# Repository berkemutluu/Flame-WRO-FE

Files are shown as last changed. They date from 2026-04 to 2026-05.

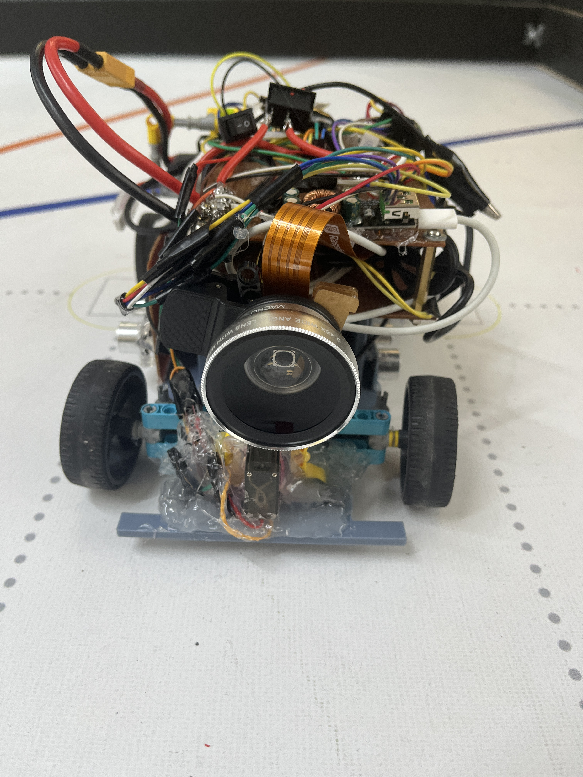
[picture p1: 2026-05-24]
Car_Photos/front.jpeg

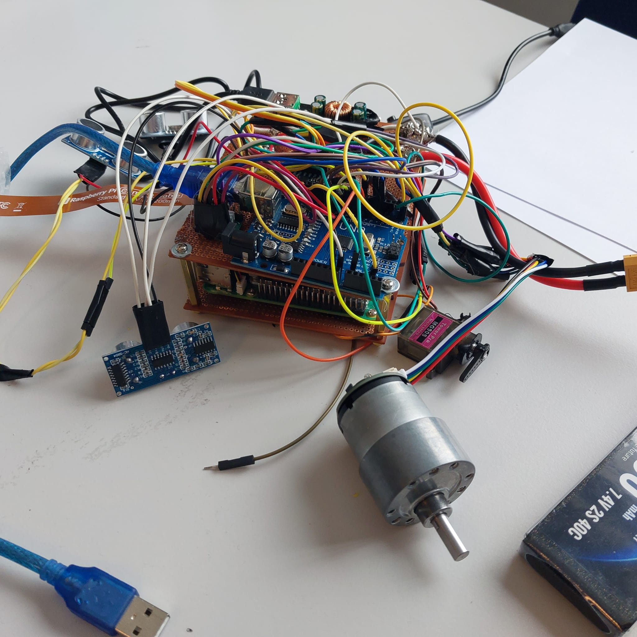
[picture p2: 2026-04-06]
Car_Photos/circuit-left.jpeg

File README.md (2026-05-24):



# WRO 2026: Future Engineers - Flame



## Table of Contents 

1. [Overview](#overview) 
2. [Design Process](#Design-Process)
3. [Car Photos](#carphoto)
4. [Mobility Management](#Mobility-Management)
    - [Chassis](#Chassis)
    - [Assembly Instructions](#assembly-instructions) 
    - [Driving Motor and Gearing](#Driving-Motor-and-Gearing)
    - [Steering and Differential Mechanism](#Steering-Mechanism)
    - [Battery](#Power-supply)
    - [Controllers](#Controllers)
    - [Sensors](#Sensors)
    - [Camera](#camera)
    - [Schematics](#schematics) 
    - [Components List](#components-list) 
5. [Software](#software) 
    - [Software Development](#software-development)
    - [Libraries Used in Runtime Files](#libraries-used-in-runtime-files)
    - [Programming Languages](#programming-languages) 
    - [Dependencies](#dependencies) 
    - [Repository Layout](#repository-layout)
    - [Code Installation and Run Guide](#code-installation-and-run-guide)
    - [Open Challenge](#open-challenge)
    - [Obstacle Challenge](#obstacle-challenge)
6. [System Thinking and Engineering Decisions](#system-thinking-and-engineering-decisions)
7. [Utilities](#utilities) 
    - [Failsafe Mechanisms](#failsafe)
    - [Debugging Tools](#debugging-tools) 
    - [Web Debug Interface](#web-debug-interface)
8. [Team Photos](#team-photos) 
9. [Demonstration Videos](#demonstration-videos) 
10. [Contributors](#contributors) 
11. [Resources](#sources) 

## Overview



Welcome to the official GitHub repository for Flame from Türkiye. This project documents the development of our autonomous vehicle designed to compete in the 2026 World Robot Olympiad (WRO) Future Engineers competition.



Our objective was to develop a high-performance autonomous vehicle capable of navigating complex tracks, avoiding obstacles, and recognizing traffic signals using OpenCV. For the 2026 season, we focused on a dual-controller architecture combining the high-speed image processing of a Raspberry Pi 5 with the real-time reliability of an Arduino Nano R4.

## Design Process

We moved through two major phases to reach our current build:

### Phase 1 (The LEGO Prototype): 

574065354-382b4c37-0c35-4aa0-9f4c-a3c25c82d3e3

574064939-b4bac3a6-0208-45d2-a44d-260d70b5efed-2

Initially, we built a frame using LEGO components and N20 Micro Gear Motor with an encoder. While excellent for rapid prototyping, the N20 motors lacked the torque required for consistent low-speed movement, and the LEGO frame exhibited structural flex under high-speed turns. Additionally, the placement of our micro servo to the lego chassis proved to be a challenge.

From this phase, we took note of what we need to improve:

- Soldering, instead of WAGO Connectors
    - These WAGO connectors really save time and effort when connecting components, but takes up a lot of unnecessary space. It was also nearly impossible to keep the wiring organized with these connectors in place.
- Chassis flex and play at joints: under acceleration and cornering, small connection tolerances introduced steering drift.
- Limited packaging freedom: The fixed structure of LEGO pieces limited our flexibility, making it challenging to position the electronics and sensors with the precision we aimed for.
- Center-of-mass inconsistency: battery and board placement options were limited, which affected balance between runs.
- Mounting rigidity for non-LEGO parts: integrating the motor, servo, and custom electronics required adapters and workarounds. 

### Phase 2 (The Custom 3D-Printed Build):

To solve the rigidity issues and to completely utilize the space we have, we designed a custom 3D-printed chassis. This allowed for a lower center of gravity and dedicated mounting points for the camera, steering, differential modules and sensors, significantly solving our problems. In short, Prototype 2 directly addressed the Phase 1 pain points: it improved rigidity, enabled cleaner wire/electronics routing, and gave us intentional component placement for better balance and repeatability. The robot is made of 3 parts: chassis, movement modules and electronics. The walls located in the center of the chassis houses the motor, while providing structual rigidity for the sandwich board of electronics mounted at the top. We designed the front and the back according to the measurements of our lego modules, resulting in a good placement. We adress the aspects of these in detail in the following chapters



### Car Photos

Here are our official photos of our car:






For high resolution pictures, please visit: [Car Photos](#carphoto)

### Mobility Management 

### Chassis

For fast prototyping, we first used lego for our chassis. Using a lego technic crane as an example we developed a small car-like chassis. However, this proved limiting for the robot: issues with accuracy and structural sag reduced its performance, while the lack of true customizability made it difficult to position electronics as needed and prevented us from using the available space efficiently. Additionally we couldn't really place electronics where we wanted, because of the lack of real customasibility. So, we wanted to go with a 3d printed chassis. First we wanted to test the motor and differential placement, and how it holds the weight our robot. This first version was designed to have a steering system that was 3d printed. But since we changed this, we also changed our chassis. We realized that our previously built circuit—a two-layer copper “sandwich” board—needed a more stable and secure mounting. So with these in mind, we extended the motor mounting walls to the side to provide a stable place to mount the electronics, achiveing a good center of mass. These side walls also enabled us to mount the side ultrasonic sensors in Version 2. 

The chassis we inspired from:

WhatsApp Image 2026-02-14 at 15 19 25

Lego Chassis:

574065354-382b4c37-0c35-4aa0-9f4c-a3c25c82d3e3

First Version - 3D Printed:



Second Version - 3D printed; with more structural stability which includes additional side walls for the electronics and the side ultrasonic sensors:



For more sketches of the chassis please visit the [3d-print files](./3d-print%20files/)

### Tires:

In our tests we compared 3 different tires from 2 different manufacturers. We tested the tires that were included in the spike prime lego set, standard tires from clementoni and onother set from the EV3 set.  Because of their lack of traction, we could not achieve good results with with the blue spike tires. Instead; we used the heavy-duty ev3 lego tires which have much better traction for the rear tires because of them being flexible rubber. Meanwhile, for the steering axle we used hard ones from clementino with grooves. 







### Assembly Instructions

To reproduce our robot, follow the sequence below.

1. **Prepare all files and parts**
   - 3D print all chassis parts from [`3d-print files`](3d-print%20files):
     - `chassis.stl`
     - `servo_adapter.stl`
     - `dc-motor_adapter.stl`
   - Open the wiring design in [`Schematic/wro.fzz`](Schematic/wro.fzz) with the Fritzing desktop app.
   - Download and prepare the LEGO module manuals from [`lego models && instructions`](lego%20models%20%26%26%20instructions):
     - `differential.pdf`
     - `steeringa.pdf`
   - Confirm all electronics and mechanical items from the Components List are available.

2. **Assemble the electronics**
   - Wire every component according to the [Schematics](#schematics) section and `Schematic/wro.fzz`.
   - Mount the control boards, regulators, and wiring on the top sandwich board.
   - Secure parts with screws/zip ties and use silicone supports where required.
   - Keep wiring away from moving drivetrain and steering parts.



3. **Build the LEGO modules**
   - Build the differential module from `differential.pdf`.
   - Build the steering module from `steeringa.pdf`.
   - Verify both modules move smoothly before mounting.

Differential:



Steering:



4. **Final mechanical integration**
   - Mount the JGB37-520 motor to the chassis center wall with M3 screws.
   - Connect the motor to the differential via the printed motor adapter.
   - Mount differential and steering modules on the chassis using silicone supports.
   - Connect the servo horn to the LEGO steering module and check full travel.
   - Install the sandwich board on the upper supports and route all cables cleanly.
   - Connect the battery last and confirm emergency access to the main power switch.



### Driving Motor and Gearing

 In our first LEGO prototype, we used an N20 6V motor, but it proved too small and lacked sufficient torque for our robot. As a result, the robot moved very slowly and responded poorly to low-speed commands, sometimes failing to move at all when a slow motion was required. We didn't want to use a 12v motor first becuase our battery was 7.4 volts. After some research, we realized that the motor driver, the L298N, might be part of the problem. Due to its low efficiency, it was not able to deliver enough power for proper performance. It also caused some voltage sag. The L298 family dissipates about 1.4V as heat, which further reduces efficiency. In addition, the minimum PWM value for speed control did not provide a smooth or usable range for precise adjustments. So we first tried to change the driver to a much more efficent, space saving and advanced component, the DRV8874. We tried it with advanced pwm controls but we couldn't solve it. The last option for us was upgrading the motor to the JGB37-520 which is 12v. We intentionally bought a high rpm version, so we could give it the same 7.4v but it could deliver the same speed we want, while increasing the torque. This was a success. This motor really outperformed the old n20 and delivered great driving to our robot. We used two m3 screws to attach this motor to our chassis, and a lego adapter to connect to motor to the differential module. This way we achieved a 1:1 gear ratio, motor starts at much lower PWM values and the braking distance is much shorter.

Old L298N:


New DRV8874:



Old n20 6V

We switched from the L298N to the DRV8874 before eventually upgrading the motor itself. The DRV8874 is a significant improvement: it is far smaller, has near-zero drop voltage (vs. ~1.4 V on the L298N), and supports efficient PWM control with a much wider effective duty-cycle range at low speeds.

### Steering and Differential Mechanism

We wanted to use steering and differential module that were 3d printed, but after several prints the parts did not hold up and caused anomalies. 

Expected outcome:





Broken guide rail after the first try:



After this experience, we decided to stick with lego for these modules. Lego parts were much more durable due to them being injection molded. Then we designed them and mounted them on the chassis with silicone.





### Battery



We use a 7.4 V-Lithium-polymer battery as our main power supply.
Per our research, we did not want to use a 11.1 V Lipo, as this one is very heavy, compared to the 2-cell version. We wanted to use a high-capacity one, becuase the Raspberry Pi is very Power-hungry when doing image processing. 
The on/off switch is located directly on the top of the robot for ease of access in an emergency. The step down convertor powers all of our sensors and motor at 5v. Also to not put strain on the LM2596, we used a high capacity PD 3.0 compatible voltage regulator board to power the pi. The arduino gets its power by the usb-a to usb-c cable along with serial communication with the pi.

See the schematics for details on connections.
[Schematics](#schematics)

#### Power Budget

To ensure the battery and regulators can handle the full electrical load, we estimated the peak and average current draw for each subsystem:

| Component | Supply Rail | Avg. Current | Peak Current |
|---|---|---|---|
| Raspberry Pi 5 (8GB, image processing) | 5 V (PD 3.0 board) | ~2.0 A | ~3.0 A |
| Arduino Nano R4 | 5 V (via USB-C from Pi) | ~30 mA | ~100 mA |
| JGB37-520 Motor (at 7.4 V) | 7.4 V (direct) | ~0.8 A | ~3.0 A (stall) |
| MG90S Servo | 5 V (LM2596) | ~150 mA | ~600 mA |
| HC-SR04 × 3 Ultrasonic Sensors | 5 V (XL4016) | ~45 mA | ~45 mA |
| MPU6050 IMU | 3.3 V (via Arduino) | ~4 mA | ~4 mA |
| TCS3200 Color Sensor | 5 V (XL4016) | ~2 mA | ~2 mA |
| DRV8874 Motor Driver (quiescent) | 7.4 V | ~1 mA | ~1 mA |

**5 V sensor rail (XL4016):** ~200 mA average — well within the 5 A rated capacity.

**Pi supply (PD 3.0 board):** Up to 3 A peak — we selected a QC 4.0/3.0 compatible module rated for 6–35 V input so it efficiently steps down from 7.4 V without the drop-voltage penalty of a linear regulator.

**Motor rail (7.4 V direct):** Average ~0.8 A, brief stall events up to ~3 A. The DRV8874 is rated for 3.5 A continuous / 5 A peak — adequate margin.

**Battery runtime estimate:** With a 3300 mAh cell and an average total draw of approximately 3.5 A across all rails, the theoretical runtime is ~56 minutes per charge. In practice we rotate between two battery packs between rounds.

We deliberately chose the 2-cell (7.4 V) LiPo over a 3-cell (11.1 V) because the 3-cell variant weighs roughly 30–40 g more for the same capacity and would require an additional high-power step-down stage for the motor. The 2-cell voltage is sufficient for the JGB37-520 at the RPM we need (we purchased the high-RPM variant specifically to offset the lower voltage).

### Controllers

For this season, we used a raspberry pi 5 and an arduino nano r4. We evaluated a single-controller design (Pi only), but kept a **dual-controller architecture** because actuator timing is more stable when low-level hardware control remains on a microcontroller.

#### Why two controllers?

- **Raspberry Pi 5 (high-level controller):**
  - Captures camera frames
  - Runs wall following, lap/section counting, and obstacle logic
  - Hosts the Flask web dashboard for live tuning and telemetry
  - Sends compact drive/steer commands to Arduino at fixed intervals

- **Arduino Nano R4 (real-time actuator controller):**
  - Executes steering servo commands immediately
  - Drives DC motor direction/PWM pins with low and predictable latency
  - Parses serial commands safely and applies bounds before output

This split lets the Pi focus on heavy image processing while Arduino handles deterministic motor/servo control.

#### Communication design (Pi ↔ Arduino)

We tested two serial methods:

1. **GPIO UART (TX/RX pins + level shifter)**  
   Not reliable in our setup because of 3.3 V (Pi) to 5 V (Arduino) level differences and intermittent link failures.

2. **USB serial (Pi USB-A to Arduino USB-C)**  
   This proved stable and simpler to maintain, so it became our final design.

Command flow is one-way for control:
- Pi sends line-based commands such as `STEER:<value>` and `DRIVE:<value>`
- Arduino validates and applies commands to hardware outputs

The link runs at **9600 baud** with a control update cadence around **20 Hz** (`send_interval = 0.05 s`).

#### Startup behavior and reliability

When USB serial is opened, Arduino may reset. To prevent unsafe movement during this phase, we use a startup handshake and safe defaults:

- Arduino starts with motor output in stop/coast state
- Pi waits for serial readiness before normal command streaming
- Control commands are only trusted after parser/connection readiness

This sequence avoids accidental motion during boot and makes power-up behavior repeatable in competition conditions.

### Sensors

Our car is equipped with a total of four sensors, not including the camera. Three of them are ultrasonic sensors, which allow for the detection of nearby obstacles.
In addition our vehicle has an IMU, the MPU6050, which is located in the top center of the robot.
Our IMU helps measure rotational movements, providing more precise control during straight sections and turns.

We have three ultrasonic sensors (hc-sr04) to measure distances to the left, the front and the right. In the opening race, some of the streets can be narrow. To avoid hitting a wall, the sensors detect the robot getting too close.

To run rather reliable turns and to go straight no matter which starting place, we use MPU6050 IMU sensor. 
This sensor has a gyroscope, an accelerometer and a compass onboard, but we only utilize the gyro.
However, gyroscopes tend to drift, when mounted on moving vehicles, that is why we use this data combined with the camera.

#### Sensor Calibration

**Ultrasonic sensors (HC-SR04):** The HC-SR04 outputs a distance in centimeters based on the echo pulse duration. We verified the accuracy by measuring a known distance of 20 cm in a controlled environment and confirming the returned value matched within ±1 cm. No software offset was needed.

**IMU (MPU6050) — gyroscope:** We initialize the IMU at robot startup while the robot is stationary. The first 100 readings are averaged to compute the zero-rate bias for each axis, which is then subtracted from subsequent readings. This removes the static offset and reduces apparent drift during straight driving.

**Camera HSV color thresholds:** The web dashboard (Flask UI) exposes all HSV lower and upper bounds for red, green, orange, and blue in real time. We calibrate under competition lighting by placing a pillar or line marker in the camera view and adjusting bounds using the live MJPEG stream until detection is stable and noise-free across at least 30 consecutive frames. Calibrated values are saved to `config.json`.

### Camera

We wanted to use a high quality camera, which has a wide angle of view and is compatible with OpenCV. The native Raspberry Pi Camera 3 suited all of our needs, on paper. In reality despite it being a wide angle camera, it was not enough for the obstacle round. The objects did not sometimes appear on the camera view, which causes problems. 

To solve this, we added a **0.45x wide-angle 37mm clip-on lens** in front of the Raspberry Pi Camera 3 module. This lens increases the visible area in front of the robot, especially at close range where obstacle pillars were previously leaving the frame. With the wider field of view, near-edge obstacle detection became more reliable and gave the control loop earlier visual input for steering decisions.

front



### Schematics 

Circuit schematics and hardware layouts are available in the [Schematic folder](Schematic).

WRO Schematic

### Components List

### 1. Computing & Control

Main Controller: Raspberry Pi 5 (8GB RAM)

Cooling: Raspberry Pi 5 Active Cooler + Aluminum Heatsink Set

Storage: SanDisk Extreme Pro 32GB MicroSD Card

Power Input: USB-C Power Cable with Integrated Switch (Type-C)

Display Interface: Micro HDMI to HDMI Cable (1.5m)

Second Controller: ~~Arduino Uno r3 (clone)~~ (For the drivetrain and sensors) Changed to a arduino nano r4 for latency issues.

### 2. Perception & Sensing

Primary Camera: Raspberry Pi Camera Module 3 (Wide Angle)

Camera Connection: Standard-to-Mini Camera Ribbon Cable (20cm)

Camera Lens: 0.45x 37mm clip-on Lens

Inertial Measurement: MPU6050 6-Axis Accelerometer and Gyroscope Sensor 

Object Detection: HC-SR04 Ultrasonic Distance Sensors (3 units)

Color Detection: TCS3200 Color Recognition Sensor Module

### 3. Propulsion & Drive System

Main Drive Motor: JGB37-520 DC Gear Motor (12V, 1590 RPM)

Secondary/Testing Motor: JGA12-520 DC Gear Motor (6V, 1500 RPM)

Motor Driver: DRV8874 Single Brushed DC Motor Driver Carrier

### 4. Power Management

Battery: 3300mAh 7.4V 2S Li-Po Battery (2 units)

Voltage Regulation (Step-Down): XL4016 High-Power DC-DC Buck Converter (5A)

LM2596 DC-DC Buck Converter (3A)

Voltage Regulation (Step-Up): MT3608 Adjustable DC-DC Boost Converter (2 units)

Specialty Power: USB-C QC4.0/QC3.0 Fast Charging Module (6V-35V Input)

### 5. Wiring & Connectivity

Connectors: XT60 Male Connection Cables (12AWG)

XT60 to Banana Plug Adapter Cable

DC Barrel Jack with Terminal Block

Wiring: 14 AWG High-Flex Silicone Wire (Red and Black)

~~Rapid Wire Connection Kit (55 pieces)~~ We decided to ditch this in favor of soldering. These WAGO connectors really save time and effort when connecting components, but takes up a lot of space. Also, it was nearly impossible to tidy our wires with these connectores attached.

Management: Cable Tie/Zip Tie Set

### 6. Mechanical Hardware

Fasteners: Assorted Screw and Nut Set (200 pieces)

M2 Screws and Nuts (8mm)

M4 Screws (6mm & 12mm), Washers, and Nuts

### 7. 3D-Printed Parts

Our robot has a total of 3 pieces which are 3d printed. Theses are:

the chassis, 

MG90s servo to lego adapter

and our JGB37-520 motor to lego adapter. 
Developing these parts took a lot of trial and error mainly because of tolerances. The printed parts did not expecatations, mainly because of durability reasons, but we have fixed this by increasing the infill rate of our adapters. This way we could combine the high-quality and durable lego parts with our motors.




# Software  

## Software Development  
  
The software is split into two controllers that cooperate during every driving cycle:  
  
1. **Raspberry Pi 5 (`raspy/robot_runtime.py`, Python)**  
   - Captures frames from the Raspberry Pi camera with `picamera2`  
   - Uses OpenCV/NumPy to crop the camera view, detect wall masks, floor markers, and red/green pillars  
   - Runs the driving state machine and computes steering/speed decisions  
   - Hosts the live preview, configuration, calibration, status, and manual-test web interface  
   - Writes decision records to one JSONL log file for review after a run  
   - Sends compact serial commands to the actuator controller  
2. **Arduino Nano (`arduino_outputProxy/drive_bridge/src/main.cpp`, C++ / Arduino framework)**  
   - Receives `STEER`, `DRIVE`, and `STOP` commands over USB serial  
   - Drives the steering servo with bounded absolute angles  
   - Drives the DC motor through the configured H-bridge pins with ramp limiting and timeout stop  
   - Keeps low-level actuator timing separate from Linux scheduling on the Pi  
  
The Pi makes the navigation decisions; the Arduino executes low-latency hardware actions. The WRO 2026 rules require the vehicle to drive autonomously, follow the randomly chosen round direction, complete three laps, and in the obstacle challenge pass red pillars on the right and green pillars on the left. The software is organized around those decisions.  
  
### Libraries Used in Runtime Files  
  
#### `arduino_outputProxy/drive_bridge/src/main.cpp` (Arduino/C++)  
- `Arduino.h`  
- `Servo.h`  
  
#### `raspy/robot_runtime.py` and modules (Python)  
- Standard library: `argparse`, `glob`, `json`, `os`, `threading`, `time`, `http.server`  
- Third-party: `cv2` (OpenCV), `numpy`  
- Optional/hardware-specific: `serial` (pyserial), `picamera2`  

### Programming Languages  
  
| Controller | Language | IDE / Toolchain |  
|---|---|---|
| Raspberry Pi 5 | Python 3 | Visual Studio Code / terminal |  
| Arduino Nano | C++ (Arduino framework) | PlatformIO / Arduino toolchain |  
  
We chose **Python** for the Pi because OpenCV and Picamera2 make camera-based tuning fast. **C++** on the Arduino is used for bounded, deterministic servo and motor output.  

### Dependencies  
  
**Raspberry Pi (Python):**  
  
| Package | Version / Notes | Purpose |  
|---|---|---|
| `opencv-python` (`cv2`) | 4.x | Color masks, contours, preview overlay, JPEG encoding |  
| `numpy` | 1.x | Array operations for frame processing |  
| `pyserial` | 3.x | USB serial communication with Arduino |  
| `picamera2` | Raspberry Pi OS package | Raspberry Pi camera capture |  
  
**Arduino Nano (C++):**  
  
| Library | Source | Purpose |  
|---|---|---|
| `Servo.h` | `arduino-libraries/Servo@^1.2.2` | Steering servo PWM control |  
| `Arduino.h` | Arduino framework | Core hardware access, serial, GPIO, timers |  
  
**Build and service tools:**  
  
| Tool | Purpose |  
|---|---|
| `platformio` | Build and upload the Arduino firmware |  
| `systemctl` | Install, enable, start, stop, and inspect the Pi runtime service |  
  
### Repository Layout  
  
| Path | Purpose |  
|---|---|
| `main.py` | Root launcher that adds `raspy/` to `sys.path` and calls `robot_runtime.main` |  
| `raspy/robot_runtime.py` | Main Pi runtime, camera loop, serial link, CLI, and `RobotRunner` |  
| `raspy/vision_pipeline.py` | HSV masks, wall mask extraction, pillar contour detection |  
| `raspy/vision_types.py` | Shared `Pillar` data object and ROI helper |  
| `raspy/drive_state.py` | State machine for starting, centering, turning, tracking pillars, avoiding pillars, and done state |  
| `raspy/lap_direction.py` | Black-wall edge voting used to infer clockwise/counter-clockwise direction |  
| `raspy/settings.py` / `raspy/settings.json` | Default settings and tuned runtime configuration |  
| `raspy/control_panel.py` | Built-in HTTP control/configuration dashboard and MJPEG preview |  
| `raspy/decision_log.py` | Central JSONL decision logger, replaced on each run |  
| `raspy/install_vehicle_service.sh` | Installs the systemd service file on the Raspberry Pi |  
| `raspy/vehicle-runtime.service` | systemd unit for starting `robot_runtime.py --pillars` on boot |  
| `arduino_outputProxy/drive_bridge/src/main.cpp` | Arduino firmware for serial parsing and actuator output |  
| `arduino_outputProxy/drive_bridge/platformio.ini` | PlatformIO firmware project configuration |  
  
### Code Installation and Run Guide  
  
Use this sequence on a Raspberry Pi 5 + Arduino Nano setup.  
  
1. **Flash the Arduino controller**  
   - Install PlatformIO if `platformio` is not already available.  
   - From repository root:  
     - `cd arduino_outputProxy/drive_bridge`  
     - `platformio run --target upload`  
   - The checked-in PlatformIO environment and board are both `nanoatmega328new`.  
   - Serial monitor speed is `9600`. On startup the Arduino prints `READY`.  
  
2. **Prepare Python runtime on Raspberry Pi**  
   - From repository root:  
     - `python3 -m venv .venv`  
     - `source .venv/bin/activate`  
     - `pip install --upgrade pip`  
     - `pip install opencv-python numpy pyserial`  
   - Install `picamera2` from the Raspberry Pi OS packages if it is not already present.  
   - `robot_runtime.py` imports `cv2` during startup, so even `--print-config` requires OpenCV to be installed.  
  
3. **Connect hardware**  
   - Connect Arduino to Raspberry Pi over USB.  
   - Confirm Arduino appears as `/dev/ttyACM0` or `/dev/ttyUSB0`; auto-detect is enabled in `raspy/settings.json`.  
   - Connect and enable the Raspberry Pi camera.  
  
4. **Run the robot software**  
   - From repository root:  
     - `python3 main.py --pillars`  
   - Or run the runtime module directly:  
     - `cd raspy`  
     - `python3 robot_runtime.py --pillars`  
   - For a camera run without Arduino output:  
     - `python3 robot_runtime.py --no-serial --max-frames 20`  
   - `--no-serial` disables USB command output only; it still needs OpenCV, Picamera2, and an enabled camera.  
   - The web dashboard is served at `http://<raspberry-pi-ip>:5000/`.  
  
5. **Useful runtime options**  
   - `--config PATH` loads a different settings file  
   - `--set path=value` overrides one setting, for example `--set control.speed=120`  
   - `--save-config` writes overrides back to the settings file  
   - `--print-config` prints the effective configuration and exits  
   - `--fixed-dir -1|0|1` sets clockwise, auto, or counter-clockwise direction behavior  
   - `--web` / `--no-web` enables or disables the dashboard  
  
6. **Before track runs**  
   - Verify steering direction, motor direction, and serial port.  
   - Open `/video_feed` or the dashboard preview and confirm wall, marker, and pillar overlays.  
   - Use Color Sampling in the dashboard to tune HSV thresholds, then save with **Save Config**.  
   - Check `raspy/decision_log.jsonl` after a run to review state changes and drive decisions.  
  
7. **Optional systemd startup service**  
   - The service assumes the deployed project is at `/home/pi/program`, so the runtime path is `/home/pi/program/raspy/robot_runtime.py`.  
   - Copy or sync this repository to `/home/pi/program` before installing the service, or update `raspy/vehicle-runtime.service` to match the deployment path.  
   - Install the service from the repository checkout on the Pi:  
     - `raspy/install_vehicle_service.sh`  
   - Manage it with systemd:  
     - `sudo systemctl start vehicle-runtime.service`  
     - `sudo systemctl stop vehicle-runtime.service`  
     - `sudo systemctl enable vehicle-runtime.service`  
     - `sudo systemctl status vehicle-runtime.service`  
     - `journalctl -u vehicle-runtime.service -f`  
   - The service runs `python3 /home/pi/program/raspy/robot_runtime.py --pillars` with working directory `/home/pi/program/raspy`.  

---  

## Open Challenge  
  
The WRO 2026 Open Challenge has no traffic signs. The vehicle must drive in the randomly selected direction, complete three laps, and stop autonomously according to the round-end rules.  
  
### Strategy  
  
The implemented strategy is camera-based wall following with color-marker turn detection:  
  
1. **Frame preparation:** `PiCamera.capture_bgr` captures an RGB frame, converts it to BGR, rotates it 180 degrees when configured, and `Pipeline.crop` removes the top part of the image using `camera.crop_height`.  
  
2. **Wall detection:** `Pipeline.filter_RG_Bl` builds a dark wall mask from grayscale intensity and low HSV saturation. It excludes detected red, green, orange, blue, and pink areas so colored markers do not become wall pixels.  
  
3. **Line marker detection:** `Pipeline.filter_OB` builds orange and blue masks inside the configured `roi.line` rectangle. The state machine uses the orange/blue portions to schedule left/right turning states.  
  
4. **Round direction:** If `behavior.fixed_round_dir` is `0`, `lap_direction.find_round_dir` votes on wall-edge geometry until `behavior.round_dir_vote_threshold` is reached. A non-zero fixed direction skips the search.  
  
5. **PD steering:** In `PD-CENTER`, the controller compares the active wall portion against `pd.target_black_portion`. `pd.kp` and `pd.kd` convert the current error and previous error into a correction value.  
  
6. **State machine:** `drive_state.StateMachine` moves through `STARTING`, `PD-CENTER`, scheduled `TURNING-L` / `TURNING-R`, and finally `DONE`. When `turns_left` reaches zero, `DONE` is scheduled after `behavior.finish_delay_seconds`.  
  
7. **Output mapping:** The correction is clamped by `control.max_correction`, converted into a servo offset with `control.max_steering_offset`, bounded to `servo_min_deg..servo_max_deg`, and sent with the selected drive speed.  
  
### Turn Count and Stop Behavior  
  
The code stops through the state machine, not through a separate lap tracker. `StateMachine` initializes `turns_left` from `behavior.turns`, subtracts one when a valid direction-specific orange or blue marker schedules a turn, then schedules `DONE` once `turns_left <= 0`. In `DONE`, `RobotRunner` centers steering and sends zero drive speed.  
  
`settings.DEFAULT_CONFIG` uses `behavior.turns = 12`, which matches three laps on a four-section track. The checked-in tuned file `raspy/settings.json` currently uses `behavior.turns = 120`. The file does not label why this value is used, so it should be treated as the current tuned/test configuration, not the WRO three-lap stop value. For an official three-lap run, set `behavior.turns` to `12` or pass `--set behavior.turns=12`.  
  
---  

## Obstacle Challenge  
  
The WRO 2026 Obstacle Challenge adds red and green pillars as traffic signs. The rules require the robot to pass a red pillar on the right and a green pillar on the left.  
  
### Strategy  
  
1. **Base navigation:** The obstacle run uses the same wall mask, line-marker logic, direction voting, and PD centering as the Open Challenge.  
  
2. **Pillar detection:** `Pipeline.get_pillars` finds red and green contours after median blur and morphological cleanup. Small, narrow, short, or low-fill contours are discarded using the `contours` settings.  
  
3. **Pillar stabilization:** `RobotRunner.stabilize_pillars` keeps one closest pillar track, smooths its area with an EMA, requires confirm frames, and can hold a recently lost pillar for a few frames.  
  
4. **Ignore check:** A pillar can be ignored when orange or blue marker pixels are found inside the narrow pillar ROI. This avoids treating track markers as traffic pillars.  
  
5. **Tracking and avoiding:** In pillar rounds, a confirmed pillar can move the state machine from `PD-CENTER` to `TRACKING-PILLAR`. A larger confirmed pillar changes the state to `AVOIDING-R` for red or `AVOIDING-G` for green.  
  
6. **Avoidance correction:** Avoidance uses a first phase and second phase correction (`pillar_red_first_correction`, `pillar_red_second_correction`, `pillar_green_first_correction`, `pillar_green_second_correction`). The wall guard can override this if one wall portion becomes too high.  
  
7. **Return to center:** After `behavior.pillar_avoid_seconds`, the state machine returns to `PD-CENTER` and enforces a cooldown before another avoid decision.  

---  
  
## Raspberry Pi Software (`raspy/robot_runtime.py`) — Process Sections  
  
### Section A — Boot and initialization  
  
- Load persisted configuration from `raspy/settings.json`  
- Merge missing keys from `settings.DEFAULT_CONFIG`  
- Apply CLI overrides such as `--pillars`, `--fixed-dir`, `--set`, and web options  
- Initialize `Pipeline`, `StateMachine`, `ArduinoLink`, `PiCamera`, and `DecisionLogger`  
- Start Arduino serial, camera capture, and the optional web server  
  
`settings.ConfigLoader` also accepts a few older configuration keys (`ArduinoSerialPort`, `PD`, and `ROI`) and maps them into the current nested settings structure. New changes should use the current keys shown in `raspy/settings.json`.  
  
### Section B — Frame acquisition and preprocessing  
  
Per frame, the Pi does the following:  
  
1. Capture a frame from Picamera2  
2. Convert RGB to BGR  
3. Rotate 180 degrees when `camera.flip_180 = true`  
4. Crop using `camera.crop_height`  
5. Convert the cropped image to HSV for color masks  
  
### Section C — Vision section  
  
`vision_pipeline.Pipeline` produces the lightweight inputs used by the state machine:  
  
- Orange and blue marker portions from `roi.line`  
- Left and right wall portions from `roi.left_wall` and `roi.right_wall`  
- Red and green pillar candidates from contour area, width, height, and fill ratio  
- Optional pink parking mask helper (`filter_parking`)  
  
### Section D — State and decision section  
  
`drive_state.StateMachine` owns the high-level driving state:  
  
- `STARTING` waits for a direction or confirmed pillar condition  
- `PD-CENTER` performs normal wall following  
- `TRACKING-PILLAR` steers based on pillar x-position  
- `AVOIDING-R` and `AVOIDING-G` use timed avoidance corrections  
- `TURNING-L` and `TURNING-R` apply full correction for corner turns  
- `DONE` forces speed to zero  
  
Important behavior settings include:  
  
- `line_marker_min_portion` for orange/blue marker detection  
- `turn_delay_seconds`, `pillar_turn_delay_seconds`, and `turn_timeout_seconds` for turns  
- `pillar_track_area`, `pillar_avoid_area`, and confirm-frame settings for obstacle behavior  
- `pillar_wall_guard_threshold` and `pillar_wall_guard_correction` for wall protection during avoidance  
  
### Section E — Serial command output  
  
`ArduinoLink` sends line-oriented actuator commands:  
  
- `STEER:<int>`  
- `DRIVE:<int>`  
- `STOP`  
  
The port is auto-detected from `/dev/ttyACM*`, `/dev/ttyUSB*`, or pyserial port listing unless auto-detect is disabled. Commands are paced by `send_interval_seconds` and repeated only after `keepalive_interval_seconds` when unchanged.  
  
### Section F — Web dashboard/API section  
  
The dashboard is served by Python's built-in `ThreadingHTTPServer`:  
  
- `GET /` dashboard  
- `GET /api/status` runtime telemetry  
- `GET /api/config` active config snapshot  
- `GET /video_feed` MJPEG stream  
- `POST /api/config` update one setting path  
- `POST /api/save` persist settings  
- `POST /api/command` manual `STEER`, `DRIVE`, or `STOP`  
- `POST /api/sample`, `/api/apply_sample`, `/api/apply_samples` for color calibration  
  
### Section G — Decision logging  
  
`decision_log.DecisionLogger` writes newline-delimited JSON to one file. By default this is `raspy/decision_log.jsonl`. The file is opened with write mode on startup, so each run replaces the previous decision log instead of creating timestamped logs.  
  
Logged events include:  
  
- `session_start` and `session_stop`  
- `runtime_start` and `runtime_error`  
- `round_direction_selected`  
- `state_update`  
- sampled `drive_output` decisions  
- `config_update` and `manual_command`  
  
Each record stores lightweight inputs, the selected decision/action, and already-computed reasoning values such as wall portions, marker portions, pillar snapshot, correction, PD error, previous error, gain values, vote totals, and manual override status. Raw frames are not written to the decision log.  
  
Console status output is separate from the decision log and is controlled by `debug.log_every_seconds`. Optional frame saving is controlled by `debug.save_frames`, `debug.frame_dir`, and `debug.frame_every_seconds`; when enabled, the runtime overwrites `latest.jpg` in the configured debug frame directory instead of storing a full video history.  
  
The sections above describe responsibilities by module.  
The next flowcharts switch perspective from static sections to **runtime execution order**. These show the steps involved from startup to each control decision.  
  
### Raspberry Pi High-Level Flow  
  
```mermaid  
flowchart TD  
    A[Start robot_runtime.py] --> B[Load settings.json and CLI overrides]  
    B --> C[Init Pipeline and StateMachine]  
    B --> D[Open decision_log.jsonl replacing old file]  
    B --> E[Connect Arduino and wait for READY]  
    E --> F[Start Picamera2]  
    F --> G{Web enabled}  
    G -- Yes --> H[Start ThreadingHTTPServer]  
    G -- No --> I[Skip dashboard]  
    H --> J[Control cycle]  
    I --> J  
    J --> K[Capture crop HSV frame]  
    K --> L[Build masks and pillars]  
    L --> M[Update state machine]  
    M --> N[Compute correction speed servo]  
    N --> O[Send STEER and DRIVE]  
    O --> P[Update preview status and decision log]  
    P --> J  
```  
  
### `RobotRunner.cycle` Detailed Flow  
  
```mermaid  
flowchart TD  
    A[Capture BGR frame] --> B[Crop and convert to HSV]  
    B --> C[Measure orange blue marker ROI]  
    B --> D[Measure left right wall ROIs]  
    B --> E[Detect and stabilize pillars]  
    C --> F[StateMachine should_transition_state]  
    D --> F  
    E --> F  
    F --> G{Searching for round direction}  
    G -- Yes --> H[Add wall-edge direction vote]  
    G -- No --> I[Keep current direction]  
    H --> J[Compute correction]  
    I --> J  
    J --> K[Map correction to servo angle]  
    K --> L[Select speed for state]  
    L --> M{Manual command active}  
    M -- Yes --> N[Override servo or drive output]  
    M -- No --> O[Use automatic output]  
    N --> P[Apply serial output]  
    O --> P  
    P --> Q[Update overlay status and logs]  
```  
  
### `StateMachine.should_transition_state` Flow  
  
```mermaid  
flowchart TD  
    A[Current state and sensor portions] --> B{Scheduled state due}  
    B -- Yes --> C[Transition to scheduled state]  
    B -- Blocking wait --> Z[Hold current state]  
    B -- No --> D{STARTING}  
    D -- Pillar confirmed --> E[TRACKING-PILLAR]  
    D -- Direction known --> F[PD-CENTER]  
    D -- Otherwise --> Z  
    F --> G{Turns left <= 0}  
    G -- Yes --> H[Schedule DONE]  
    G -- No --> I{Pillar round and pillar confirmed}  
    I -- Track area --> E  
    I -- Avoid area --> J[AVOIDING-R or AVOIDING-G]  
    I -- No --> K{Line marker detected}  
    E --> L{Pillar lost}  
    L -- Yes --> F  
    L -- No --> I  
    J --> M{Avoid timer elapsed}  
    M -- Yes --> F  
    M -- No --> Z  
    K -- Blue with clockwise dir --> N[Schedule TURNING-L]  
    K -- Orange with counter-clockwise dir --> O[Schedule TURNING-R]  
    K -- Otherwise --> Z  
    N --> Z  
    O --> Z  
```  
  
### `compute_correction` Flow  
  
```mermaid  
flowchart TD  
    A[State and measured inputs] --> B{State}  
    B -- TRACKING-PILLAR --> C[Error from pillar x offset]  
    B -- PD-CENTER --> D[Error from active wall portion]  
    B -- TURNING-L --> E[Correction -1.0]  
    B -- TURNING-R --> F[Correction 1.0]  
    B -- AVOIDING-R --> G[Red avoidance phase correction]  
    B -- AVOIDING-G --> H[Green avoidance phase correction]  
    B -- STARTING or DONE --> I[Correction 0.0]  
    C --> J[PD correction kp error plus kd delta]  
    D --> J  
    G --> K{Wall guard active}  
    H --> K  
    K -- Wall too close --> L[Use guard correction]  
    K -- Clear --> M[Use phase correction]  
    E --> N[Clamp and output]  
    F --> N  
    I --> N  
    J --> N  
    L --> N  
    M --> N  
```  
  
---  
  
## Arduino Software (`arduino_outputProxy/drive_bridge/src/main.cpp`) — Process Sections  
  
### Section 1 — Hardware constants and limits  
  
- `SERVO_PIN = 6`  
- `MOTOR_IN1_PIN = 10`  
- `MOTOR_IN2_PIN = 9`  
- Optional `MOTOR_PWM_PIN = 11` for one-PWM/two-direction wiring  
- Current motor mode: `USE_TWO_PWM_MOTOR_DRIVER = true` and `USE_SOFTWARE_PWM_FOR_TWO_PWM_DRIVER = true`  
- Physical enable input is currently disabled: `USE_ENABLE_PIN = false`, with `ENABLE_PIN = 7` reserved if enabled later  
- Steering bounds: `SERVO_MIN_DEG = 15`, `SERVO_CENTER_DEG = 90`, `SERVO_MAX_DEG = 165`  
- Motor output bound: `MOTOR_MAX_PWM = 200`  
- Ramp settings: `MOTOR_RAMP_INTERVAL_MS = 20`, `MOTOR_RAMP_STEP = 2`  
- Command timeout: `COMMAND_TIMEOUT_MS = 1000`  
- Command line buffer size: `LINE_BUF_SIZE = 64`  
  
### Section 2 — Setup phase  
  
`setup()` performs deterministic startup:  
  
- Configure motor pins and optional enable pin  
- Attach and center steering servo  
- Stop motor output  
- Start serial at `9600`  
- Emit `READY` after startup delay  
  
### Section 3 — Command receive and parse phase  
  
`loop()` and `handleCommand` implement a strict parser:  
  
1. Read bytes until newline  
2. Null-terminate the line buffer  
3. Split `NAME:VALUE` at the colon  
4. Parse the integer payload with `parseIntStrict`  
5. Execute only supported commands  
  
Supported commands:  
  
- `STOP`  
- `STEER:<int>`  
- `DRIVE:<int>`  
  
### Section 4 — Actuator execution phase  
  
- `writeSteering` clamps absolute servo angle to `15..165`  
- `writeMotorPwm` clamps speed to `-200..200`  
- `updateMotorRamp` moves `currentSpeed` toward `targetSpeed` in small steps  
- If no valid command arrives for `1000 ms`, target speed returns to zero  
- If `USE_ENABLE_PIN` is enabled and the input is not active, motor target speed is forced to zero  
  
### Arduino Command Processing Flow  
  
```mermaid  
flowchart TD  
    A[Serial byte received] --> B{Is newline}  
    B -- No --> C[Append to line buffer]  
    B -- Yes --> D[Null terminate line]  
    D --> E[handleCommand]  
    E --> F{STOP command}  
    F -- Yes --> G[Center steering and stop motor]  
    F -- No --> H[Parse name and value]  
    H --> I{Valid integer value}  
    I -- No --> J[Print ERR:VALUE]  
    I -- Yes --> K{STEER or DRIVE}  
    K -- STEER --> L[Clamp and write steering angle]  
    K -- DRIVE --> M[Set bounded target speed]  
    K -- Other --> N[Print ERR:COMMAND]  
```  
  
### `updateMotorRamp` Flow  
  
```mermaid  
flowchart TD  
    A[Current speed and target speed] --> B{20 ms elapsed}  
    B -- No --> C[Keep current output]  
    B -- Yes --> D{current < target}  
    D -- Yes --> E[Increase by ramp step]  
    D -- No --> F{current > target}  
    F -- Yes --> G[Decrease by ramp step]  
    F -- No --> H[No speed change]  
    E --> I[writeMotorPwm]  
    G --> I  
    H --> I  
```  
  
### `writeMotorPwm` Flow  
  
```mermaid  
flowchart TD  
    A[Input speed] --> B[Clamp to -200..200]  
    B --> C{Outputs enabled}  
    C -- No --> D[Force speed 0]  
    C -- Yes --> E{Two PWM driver}  
    E -- Software PWM --> F[Store outputSpeed for software PWM loop]  
    E -- Hardware PWM --> G[Analog write one motor pin]  
    E -- One PWM driver --> H[Set direction pins and PWM pin]  
    D --> I[Motor pins low]  
    F --> J[updateSoftwareMotorPwm drives duty cycle]  
    G --> K[Motor output updated]  
    H --> K  
```  
  
---  
  
## Raspberry Pi ↔ Arduino Runtime Interaction  
  
```mermaid  
sequenceDiagram  
    participant Cam as Camera  
    participant Pi as Raspberry Pi robot_runtime.py  
    participant Log as decision_log.jsonl  
    participant Ard as Arduino drive_bridge  
    Cam->>Pi: RGB frame  
    Pi->>Pi: Vision masks, state machine, correction  
    Pi->>Log: State and drive decision records  
    Pi->>Ard: STEER:<angle>  
    Pi->>Ard: DRIVE:<speed>  
    Ard->>Ard: Servo and motor ramp execution  
    Pi->>Pi: Update status and video feed  
```  
  
1. The camera streams frames into Pi-side perception/control code.  
2. Pi converts each frame into steering angle and drive speed decisions.  
3. Those decisions are logged as lightweight JSONL records and sent to Arduino over USB serial at `9600` baud.  
4. Arduino parses complete command lines, validates payloads, and updates actuator outputs.  
5. In parallel, Pi publishes status, configuration, calibration controls, and MJPEG video for operators.  
  
---  
  
## System Thinking and Engineering Decisions  
  
This section documents the key software constraints, tradeoffs, and risks that shaped the current implementation.  
  
### Constraints  
  
| Constraint | Value / Limit | Impact |  
|---|---|---|
| WRO 2026 start procedure | Robot is switched on, waits, then starts after one start action | Current runtime starts immediately after launch; physical start-button wait is not implemented yet |  
| Round direction | Randomly chosen before each challenge round | Direction can be fixed with CLI/config or inferred by wall-edge voting |  
| Challenge length | Open and Obstacle rounds are three minutes | Runtime keeps decisions lightweight and avoids storing raw frames by default |  
| Obstacle rule | Red on right, green on left | State machine has color-specific avoid states and correction values |  
| Actuator timing | Linux is not deterministic for PWM | Arduino owns servo and motor output |  
| Tuning under venue lighting | HSV thresholds move with lighting | Web sampling updates color ranges without reflashing firmware |  
  
### Tradeoffs and Decisions  
  
#### Pi-only control vs. Pi + Arduino split  
The Pi has enough processing power for camera vision, but Linux timing is not the right place to generate direct motor/servo output. We keep perception and planning on the Pi and move low-level actuator execution to Arduino over a small serial protocol.  
  
#### Fixed direction vs. automatic direction voting  
The challenge direction is known before each round, so `--fixed-dir` can be used when we want deterministic setup. The automatic mode remains useful for testing because `lap_direction.find_round_dir` can vote from wall-edge geometry until the configured threshold is reached.  
  
#### Raw-data logging vs. decision logging  
The system logs decisions instead of full camera frames. This keeps one readable `decision_log.jsonl` per run with the inputs and reasoning values needed to debug state transitions, without filling storage with video data.  
  
#### Dashboard framework choice  
The dashboard uses `ThreadingHTTPServer` instead of Flask. The UI is a single embedded HTML page with JSON endpoints, which keeps the runtime dependency set small on the Raspberry Pi.  
  
### Risk Identification and Mitigation  
  
| Risk | Likelihood | Mitigation |  
|---|---|---|
| Serial port changes between boots | Medium | Auto-detect `/dev/ttyACM*`, `/dev/ttyUSB*`, then pyserial port listing |  
| Arduino receives stale commands | Medium | Firmware forces target speed to zero after `COMMAND_TIMEOUT_MS` |  
| Pillar detection flickers | Medium | EMA area smoothing, confirm frames, and lost-frame hold |  
| Colored floor markers pollute wall mask | Medium | Wall mask excludes detected red, green, orange, blue, and pink pixels |  
| Venue lighting changes HSV thresholds | High | Browser-based color sampling updates filter ranges and saves settings |  
| Decision behavior is hard to review after a run | Medium | Central JSONL decision log records state changes and sampled drive outputs |  
  
### Tests && Decisions  
  
To make the current software decisions reproducible, we keep the values that most affect behavior in `raspy/settings.json`:  
  
| Decision area | Setting / file | Current value or behavior | Reason |  
|---|---|---|---|
| Camera crop | `camera.crop_height` | `190` | Process only the lower track area used for driving |  
| Drive speeds | `control.speed`, `turn_speed`, `avoid_speed` | `160`, `155`, `115` | Slow down during obstacle handling while keeping normal pace higher |  
| Steering bounds | `servo_min_deg`, `servo_center_deg`, `servo_max_deg` | `15`, `90`, `165` | Protect steering hardware and keep command mapping predictable |  
| Direction behavior | `behavior.fixed_round_dir` | `0` | Use automatic direction search unless set for a round |  
| Marker threshold | `line_marker_min_portion` | `0.25` | Require a clear orange/blue marker signal before turn scheduling |  
| Pillar avoid trigger | `pillar_avoid_area` | `2800` | Avoid only when the pillar is close and confirmed |  
| Decision logging | `decision_log.path` | `decision_log.jsonl` | Replace one log file per run for simple review |  

---  

## Utilities  
   
   

### Failsafe Mechanisms  
   
We implemented multiple layers of failsafe protection to prevent hardware damage and ensure safe competition runs.  
   
#### Hardware Failsafes  
   
**Wire color-coding:**  
We wrapped wires with colored tape so that every wire belonging to the same subsystem shares the same color. This reduces reconnection errors when disassembling and reassembling the robot between rounds. During early testing, an unlabeled wire became detached and was difficult to trace; after introducing color coding, this type of error has not recurred.  
   
**Low-voltage indicator:**  
The LM2596 step-down module (5 V sensor rail) has an onboard LED that dims when input voltage falls below ~7.5 V. This gives us a visual warning that the LiPo cell is approaching its minimum safe voltage before the servo response degrades. We also keep a spare charged battery pack ready so we can swap within the pit stop window.  
   
**Servo mechanical limits:**  
The steering servo is constrained in firmware to an absolute range of 15°–165°. This prevents a software error from issuing a command that would physically damage the servo linkage or lego steering module.  
   
**Motor driver protection:**  
The DRV8874 provides overcurrent shutdown and thermal protection. If the motor stalls or the robot jams against a wall, the driver enters protection mode rather than burning the motor or wiring.  
   
#### Software Failsafes  
   
**Done-state stop:**  
When the state machine reaches `DONE`, the Pi centers the steering and sends zero drive speed. This keeps the vehicle from continuing after the configured turn count is complete.  
   
**Arduino speed ramp limiter:**  
The Arduino changes motor output by `MOTOR_RAMP_STEP = 2` every `MOTOR_RAMP_INTERVAL_MS = 20`. This prevents sudden torque spikes that could cause the chassis to lose traction or cause the motor adapter to slip.  
   
**Serial command validation:**  
The Arduino parser only executes commands that match the expected format (`NAME:VALUE` with a valid integer). Malformed or truncated packets are silently discarded, so a noise burst on the USB serial link cannot cause unsafe motor or servo movement.  
   
**Serial startup handshake:**  
On power-on the Raspberry Pi always resets the Arduino when it opens the serial port. We solved this with a software handshake: the Arduino emits a ready signal after startup, and the Pi waits for that signal before sending any drive commands. This prevents the robot from moving before the Pi has initialized the camera and loaded configuration.  
   
**Command timeout stop:**  
If the Arduino does not receive a valid command for `COMMAND_TIMEOUT_MS = 1000`, it forces target speed to zero. This prevents stale Pi commands from keeping the motor active after a runtime interruption.  
   

### Debugging Tools  
   
**Python (Raspberry Pi):** We use **Visual Studio Code** with the Pylance extension for development. The live web dashboard (`/` and `/video_feed`) allows us to observe the robot's perception state, adjust color thresholds, and test commands in real time without stopping the run. The MJPEG video feed (`/video_feed`) streams the annotated debug overlay directly from `raspy/robot_runtime.py` so we can diagnose wall detection or pillar detection issues without an HDMI cable.  
   
**Arduino (C++):** We use the Arduino toolchain through PlatformIO, plus a serial monitor at `9600`, to inspect incoming command strings and verify that the Pi is sending correctly formatted `STEER` and `DRIVE` packets. During hardware bring-up we also used the serial monitor to verify servo and motor responses independently of the Pi.  
   

#### Web Debug Interface  
   
Below are screenshots of our real-time debug dashboard used during testing and competition preparation:  
   
Web Debug Interface - Main Controls and Video  
   
Web Debug Interface - Calibration and Runtime Status  
   
What this interface is used for:  
   
- **Live monitoring:** We watch the MJPEG stream (`/video_feed`) with overlays to confirm wall and pillar detection quality in real time.  
- **Fast calibration:** We tune HSV bounds and camera/control parameters from the browser, then persist them with `/api/save`.  
- **Runtime diagnostics:** We inspect `/api/status` and `/api/config` output to verify state, direction, active thresholds, and serial settings before each run.  
- **Safe iteration loop:** Instead of reflashing firmware for each small adjustment, we tune through the web UI, test immediately on track, and only commit stable parameter sets.  
   
   

## Team Photos  
   
[Team Photo](https://github.com/user-attachments/assets/fc466126-dbe5-4d71-9a1d-e72979701b23)  
   

## Demonstration Videos  
   
- [Open Round](https://youtu.be/vSCUsRolfGY)   
- [Obstacle Round](https://youtu.be/aSWpX4NWNCk)  
   
   
   
   

## Contributors 👥  
   
- berkemutluu  
- ardaberkk  
   
[Team Photo](https://github.com/user-attachments/assets/fc466126-dbe5-4d71-9a1d-e72979701b23)  
   

## Resources  
- 3D Parts Development [Onshape](https://onshape.com/)  
- Ackerman Steering Mechanism [Wikipedia](https://en.wikipedia.org/wiki/Ackermann_steering_geometry)  
- [Help with Open CV](https://learnopencv.com/)  
- Lego Modules && Instruction Modules Creation [Bricklink Studio](https://www.bricklink.com/v3/studio/download.page)  
   
[Back to top](#top)

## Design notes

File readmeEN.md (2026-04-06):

**##WRO 2026: Future Engineers - Flame**
Welcome to the official repository for Flame. This project documents the development of our autonomous vehicle designed to compete in the World Robot Olympiad (WRO) Future Engineers category.

**This robot is not yet finished, this is a preliminary report of what he have currently achieved.**

## Project Overview
Our goal was to design, build, and program a small-scale autonomous vehicle capable of navigating a track, avoiding obstacles, and reacting to traffic signals using computer vision and advanced control algorithms.

## Features
Lane Detection: Real-time processing using OpenCV to identify track boundaries.

Obstacle Avoidance: Integration of ultrasonic sensors and camera depth perception to navigate around colored blocks.

PID Control: Smooth steering and speed regulation using Proportional-Integral-Derivative controllers and using the MPU6050 IMU.

Traffic Sign Recognition: Utilizing a trained model to identify "Turn Left," "Turn Right," and "Stop" signals.

## Bill of Materials (BOM)
### 1. Computing & Control

Main Controller: Raspberry Pi 5 (8GB RAM)

Cooling: Raspberry Pi 5 Active Cooler + Aluminum Heatsink Set

Storage: SanDisk Extreme Pro 32GB MicroSD Card

Power Input: USB-C Power Cable with Integrated Switch (Type-C)

Display Interface: Micro HDMI to HDMI Cable (1.5m)

### 2. Perception & Sensing

Primary Camera: Raspberry Pi Camera Module 3 (Wide Angle)

Camera Connection: Standard-to-Mini Camera Ribbon Cable (20cm)

Inertial Measurement: MPU6050 6-Axis Accelerometer and Gyroscope Sensor (2 units)

Object Detection: HC-SR04 Ultrasonic Distance Sensors (2 units)

Color Detection: TCS3200 Color Recognition Sensor Module

### 3. Propulsion & Drive System

Main Drive Motor: JGB37-520 DC Gear Motor (12V, 1590 RPM)

Secondary/Testing Motor: JGA12-520 DC Gear Motor (6V, 1500 RPM)

Motor Driver: DRV8874 Single Brushed DC Motor Driver Carrier

### 4. Power Management

Battery: 3300mAh 7.4V 2S Li-Po Battery (2 units)

Voltage Regulation (Step-Down): * XL4016 High-Power DC-DC Buck Converter (5A)

LM2596 DC-DC Buck Converter (3A)

Voltage Regulation (Step-Up): MT3608 Adjustable DC-DC Boost Converter (2 units)

Specialty Power: USB-C QC4.0/QC3.0 Fast Charging Module (6V-35V Input)

### 5. Wiring & Connectivity

Connectors: * XT60 Male Connection Cables (12AWG)

XT60 to Banana Plug Adapter Cable

DC Barrel Jack with Terminal Block

Wiring: * 14 AWG High-Flex Silicone Wire (Red and Black)

Rapid Wire Connection Kit (55 pieces)

Management: Cable Tie/Zip Tie Set

### 6. Mechanical Hardware

Fasteners: * Assorted Screw and Nut Set (200 pieces)

M2 Screws and Nuts (8mm)

M4 Screws (6mm & 12mm), Washers, and Nuts

## Software Architecture
The software is primarily written in Python, leveraging the following libraries:

OpenCV: For image processing, color masking, and Canny edge detection.

NumPy: For high-performance mathematical operations on image arrays.

ServoTimer2: For high-accuracy servo operations.

### Logic Flow

Perception: Capture frames and apply a perspective transform (Bird's Eye View).

Processing: Filter colors (orange/blue lines) and calculate the deviation from the center.

Decision: The PID controller calculates the necessary steering angle based on the error.

Action: Pulse Width Modulation (PWM) signals are sent to the motors via DRV8874.

## Repository Structure
Plaintext
├── src/                # Core source code (Python scripts)
│   ├── main.py         # Entry point for the robot
│   ├── vision.py       # OpenCV lane and object detection
│   └── control.py      # PID and motor logic
├── models/             # Trained AI models for sign recognition
├── hardware/           # 3D models (STL) and circuit diagrams
├── docs/               # Engineering journals and photos
└── README.md
## Setup and Installation
To run the code locally for testing or on your robot:

Clone the repository:

Bash
git clone https://github.com/berkemutluu/flame-wro-fe.git
Install dependencies:

Bash
pip install opencv-python numpy servotimer2

Run the main application:

Bash
python src/main.py
## Engineering Journal

## Evolution of the Powertrain
Our development process involved significant iterations in both hardware and chassis design to meet the speed and torque requirements of the WRO track.

### Phase 1: The LEGO Prototype

Chassis: Modified LEGO-based frame.

Motor: 6V N20 Micro Gear Motor.

Outcome: Unsuccessful. * Reasoning: While easy to prototype, the N20 motors lacked the necessary torque to move the chassis consistently at low speeds, and the top speed was insufficient for competitive lap times. The LEGO frame also exhibited too much flex under stress, affecting steering alignment.

### Phase 2: Custom High-Torque Build

Chassis: Custom 3D-printed rigid chassis for better weight distribution and sensor mounting.

Motor: JGB37-520 High-Torque DC Motor (Rated for 12V, 1590 RPM).

Power Solution: Due to weight and space constraints, we opted for a 7.4V LiPo battery instead of a bulkier 12V 3 cell source.

Outcome: Success.

Technical Detail: By running the 12V motors at 7.4V, we effectively operate at approximately 60–70% of the rated RPM. This trade-off was intentional: it provided a more manageable speed for our computer vision processing while maintaining significantly higher torque and structural stability compared to the N20/LEGO setup.

### Technical Challenges Overcome

PWM Calibration: We adjusted our Pulse Width Modulation (PWM) signals to account for the 7.4V limit, ensuring the PID controller had enough headroom to maintain constant speed during turns.

Voltage Sag: Documented the correlation between battery discharge and motor RPM, implementing a "battery compensation" factor in our motor control code.

Chassis Rigidity: The switch to a 3D-printed frame allowed for a lower center of gravity, reducing "body roll" which previously caused camera feed instability.

## License
This project is licensed under the MIT License - see the LICENSE file for details.

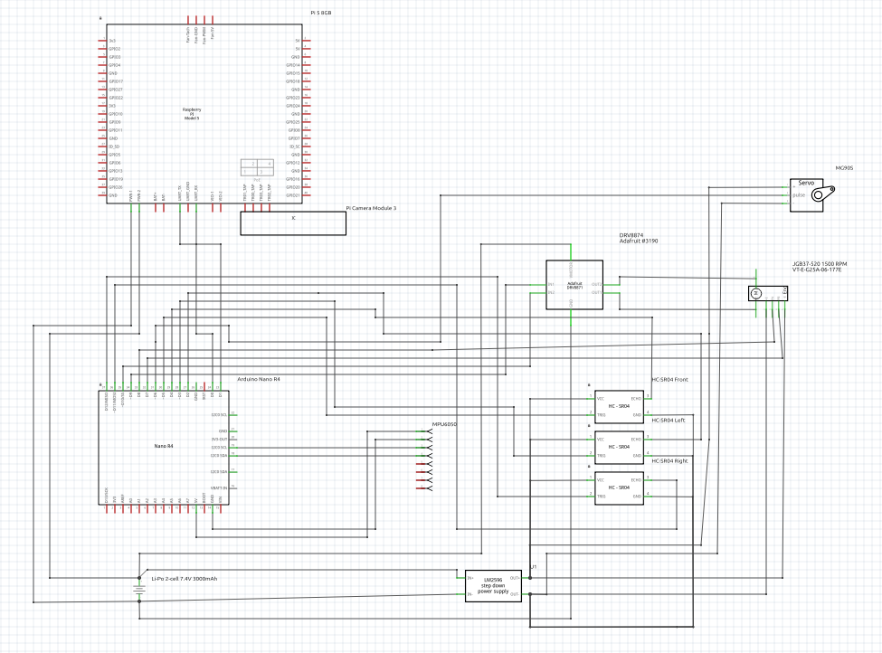
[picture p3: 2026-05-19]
Schematic/WRO Schematic.png

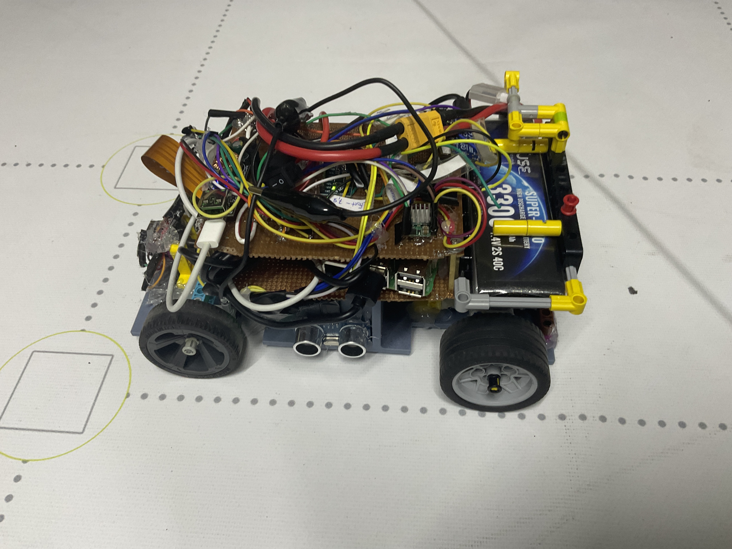
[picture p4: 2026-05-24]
Car_Photos/Left.jpg

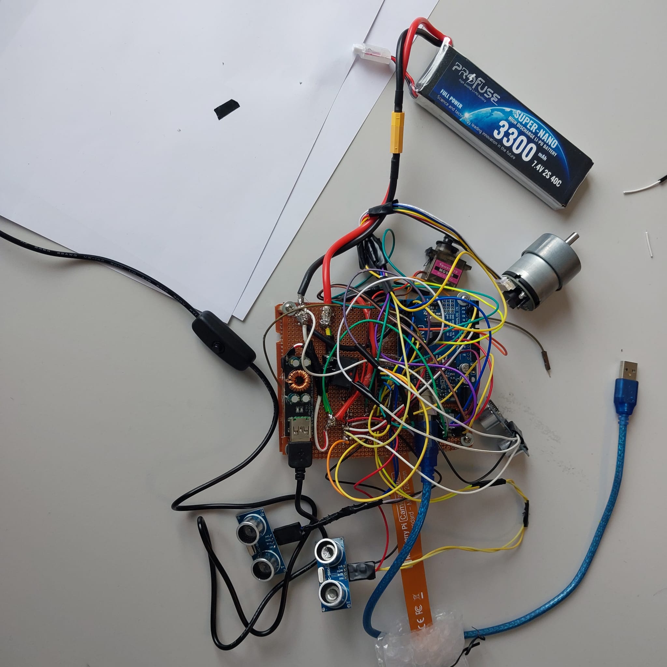
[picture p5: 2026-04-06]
Car_Photos/circuit-top.jpeg

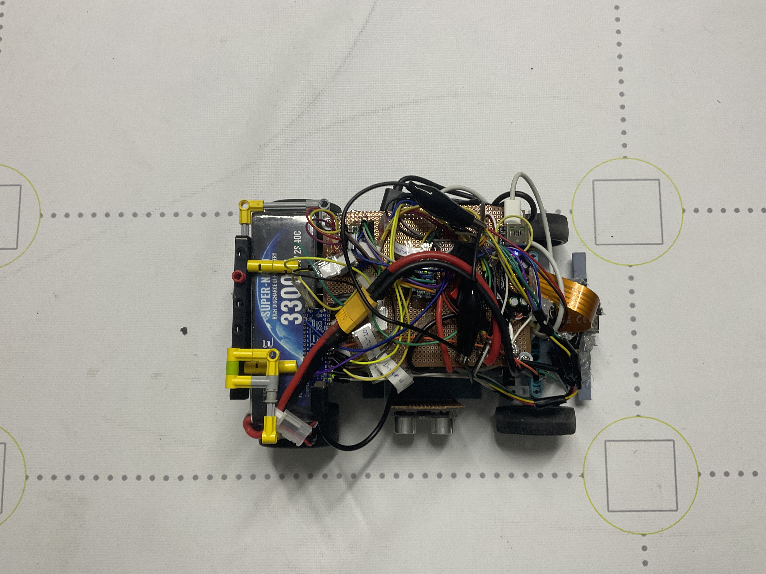
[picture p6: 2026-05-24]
Car_Photos/Top.jpg

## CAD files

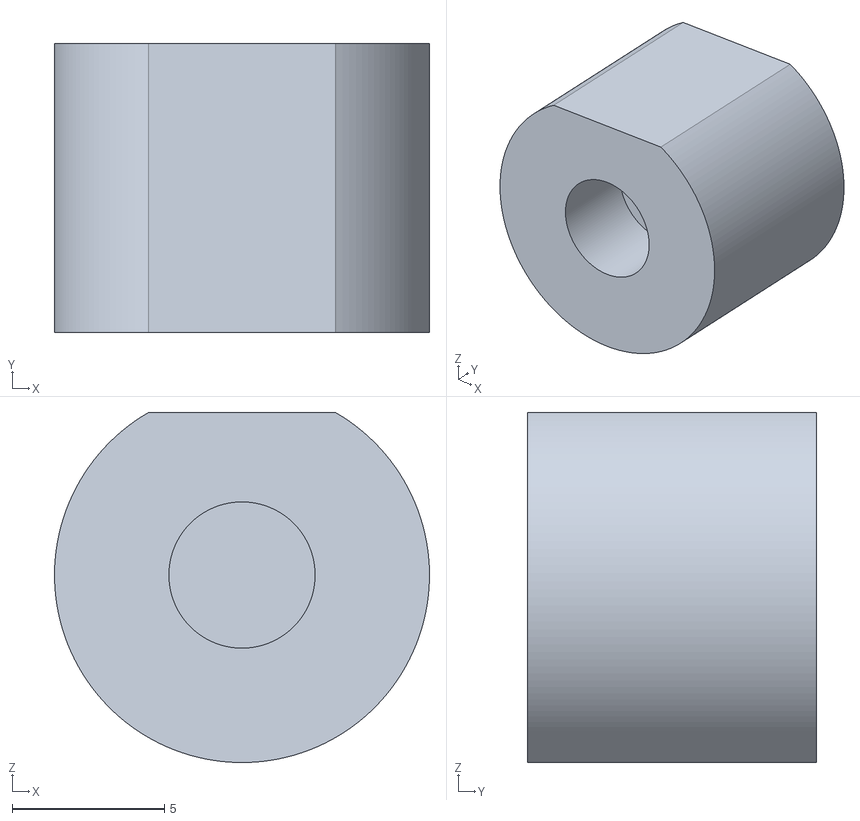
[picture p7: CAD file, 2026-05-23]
3d-print files/servo_adapter.stl
12.3 x 9.50 x 11.5

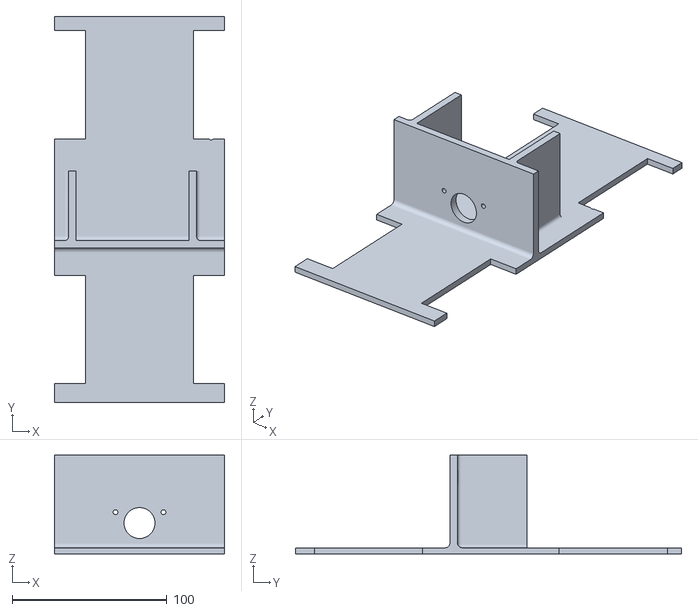
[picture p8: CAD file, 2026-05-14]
3d-print files/chassis.stl
110.0 x 250.0 x 64.0

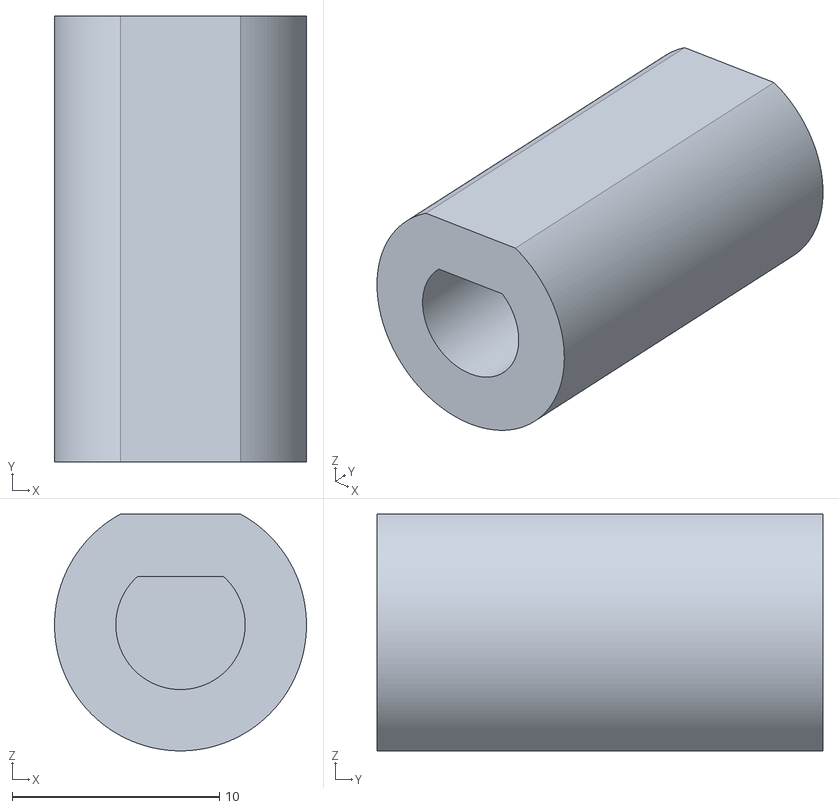
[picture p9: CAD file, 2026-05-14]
3d-print files/dc-motor_adapter.stl
12.2 x 21.5 x 11.4

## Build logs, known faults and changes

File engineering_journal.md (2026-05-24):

# Engineering Journal

**This Journal is out of date. Review README.md to see the current status.**

As of 14th of May, we have finished the code of the open round. We have recorded a good amount of accuracy and the robot functions as expected. We have now moved on to the obstacle round.

Because of some compability issues between the clone arduino uno and raspberry pi, we have decided to change to an original arduino nano r4. The clone arduino ran at 16 mHz with 8-bit architecture compared with the new nano, 48mHz and 32-bit processor. This significantly solved our problems of latency between the wall detection and the steering+driving output. 

WhatsApp Image 2026-05-09 at 12 30 58

We have released our wall tracking code on 7th of May. This code utilizes opencv to capture video and a "wall detection" algoritihm along with red and green obstacle detection capability. We have selected region of interests to crop the camera feed in half to avoid unwanted detections. The web interface of the pi uses flask to create a dashboard to see the live camera feed and to calibrate speed, colors and sensitivity. According to this the pi sends serial commands through the usb interface to the arduino, activating and driving the main motor and servo. The control logic uses a proportional_derivative codebase. Steering of the robot is proportional to the error of the robot.

On the 5th of May; we have put together our robots chassis with the electronics, sensor, motors, differential and steering systems. (We might reevaluate and possibly change these in the future.) We are currently working on the coding of our arduino board and pi's opencv modulation.




As of April 28,we have designed and 3D printed our robot's chassis and integrated the motor into it. Additionally, we have developed a differantial and steering system optimized for reducing the turning radius of our robot.




WhatsApp Image 2026-04-02 at 15 32 51 (2)

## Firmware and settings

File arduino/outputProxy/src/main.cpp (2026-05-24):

#include <Arduino.h>
#include <Servo.h>

// Defaults match your original wiring.
constexpr uint8_t SERVO_PIN = 6;

// true:  two PWM H-bridge inputs, like the original sketch: IN1=10, IN2=9
// false: one PWM/enable pin plus two direction pins
constexpr bool USE_TWO_PWM_MOTOR_DRIVER = true;
constexpr bool USE_SOFTWARE_PWM_FOR_TWO_PWM_DRIVER = true;
constexpr uint8_t MOTOR_IN1_PIN = 10;
constexpr uint8_t MOTOR_IN2_PIN = 9;
constexpr uint8_t MOTOR_PWM_PIN = 11;

// Set this to true if you wired a physical enable switch to ENABLE_PIN.
constexpr bool USE_ENABLE_PIN = false;
constexpr uint8_t ENABLE_PIN = 7;

constexpr int SERVO_CENTER_DEG = 90;
constexpr int SERVO_MIN_DEG = 15;
constexpr int SERVO_MAX_DEG = 165;

constexpr int MOTOR_MAX_PWM = 200;
constexpr uint16_t MOTOR_RAMP_INTERVAL_MS = 20;
constexpr int MOTOR_RAMP_STEP = 2;
constexpr uint16_t SOFTWARE_PWM_PERIOD_US = 2000;
constexpr uint16_t COMMAND_TIMEOUT_MS = 1000;
constexpr size_t LINE_BUF_SIZE = 64;
constexpr bool PRINT_COMMAND_ACKS = false;

Servo steeringServo;

char lineBuf[LINE_BUF_SIZE];
size_t lineLen = 0;

int targetSpeed = 0;
int currentSpeed = 0;
int outputSpeed = 0;
int targetAngle = SERVO_CENTER_DEG;
unsigned long lastRampMs = 0;
unsigned long lastCommandMs = 0;

bool outputsEnabled() {
  return !USE_ENABLE_PIN || digitalRead(ENABLE_PIN) == HIGH;
}

int clampInt(int value, int lo, int hi) {
  return max(lo, min(hi, value));
}

void writeSteering(int absoluteAngleDeg) {
  targetAngle = clampInt(absoluteAngleDeg, SERVO_MIN_DEG, SERVO_MAX_DEG);
  steeringServo.write(targetAngle);
}

void writeMotorPwm(int speed) {
  speed = clampInt(speed, -MOTOR_MAX_PWM, MOTOR_MAX_PWM);
  if (!outputsEnabled()) {
    speed = 0;
  }

  if (USE_TWO_PWM_MOTOR_DRIVER) {
    if (USE_SOFTWARE_PWM_FOR_TWO_PWM_DRIVER) {
      outputSpeed = speed;
      if (speed == 0) {
        digitalWrite(MOTOR_IN1_PIN, LOW);
        digitalWrite(MOTOR_IN2_PIN, LOW);
      }
      return;
    }

    if (speed > 0) {
      analogWrite(MOTOR_IN1_PIN, speed);
      digitalWrite(MOTOR_IN2_PIN, LOW);
    } else if (speed < 0) {
      digitalWrite(MOTOR_IN1_PIN, LOW);
      analogWrite(MOTOR_IN2_PIN, -speed);
    } else {
      analogWrite(MOTOR_IN1_PIN, 0);
      analogWrite(MOTOR_IN2_PIN, 0);
      digitalWrite(MOTOR_IN1_PIN, LOW);
      digitalWrite(MOTOR_IN2_PIN, LOW);
    }
    return;
  }

  if (speed > 0) {
    digitalWrite(MOTOR_IN1_PIN, HIGH);
    digitalWrite(MOTOR_IN2_PIN, LOW);
  } else if (speed < 0) {
    digitalWrite(MOTOR_IN1_PIN, LOW);
    digitalWrite(MOTOR_IN2_PIN, HIGH);
  } else {
    digitalWrite(MOTOR_IN1_PIN, LOW);
    digitalWrite(MOTOR_IN2_PIN, LOW);
  }

  analogWrite(MOTOR_PWM_PIN, abs(speed));
}

void updateSoftwareMotorPwm() {
  if (!USE_TWO_PWM_MOTOR_DRIVER || !USE_SOFTWARE_PWM_FOR_TWO_PWM_DRIVER) {
    return;
  }

  int speed = clampInt(outputSpeed, -MOTOR_MAX_PWM, MOTOR_MAX_PWM);
  if (speed == 0) {
    digitalWrite(MOTOR_IN1_PIN, LOW);
    digitalWrite(MOTOR_IN2_PIN, LOW);
    return;
  }

  static unsigned long periodStartUs = micros();
  unsigned long nowUs = micros();
  unsigned long elapsed = nowUs - periodStartUs;
  if (elapsed >= SOFTWARE_PWM_PERIOD_US) {
    periodStartUs = nowUs;
    elapsed = 0;
  }

  unsigned int dutyUs = (static_cast<unsigned long>(abs(speed)) * SOFTWARE_PWM_PERIOD_US) / MOTOR_MAX_PWM;
  bool on = elapsed < dutyUs;
  if (speed > 0) {
    digitalWrite(MOTOR_IN1_PIN, on ? HIGH : LOW);
    digitalWrite(MOTOR_IN2_PIN, LOW);
  } else {
    digitalWrite(MOTOR_IN1_PIN, LOW);
    digitalWrite(MOTOR_IN2_PIN, on ? HIGH : LOW);
  }
}

void stopMotor() {
  targetSpeed = 0;
  currentSpeed = 0;
  writeMotorPwm(0);
}

void stopAll() {
  writeSteering(SERVO_CENTER_DEG);
  stopMotor();
}

void updateMotorRamp() {
  unsigned long now = millis();
  if (now - lastRampMs < MOTOR_RAMP_INTERVAL_MS) {
    return;
  }
  lastRampMs = now;

  if (currentSpeed < targetSpeed) {
    currentSpeed = min(currentSpeed + MOTOR_RAMP_STEP, targetSpeed);
  } else if (currentSpeed > targetSpeed) {
    currentSpeed = max(currentSpeed - MOTOR_RAMP_STEP, targetSpeed);
  }

  writeMotorPwm(currentSpeed);
}

bool parseIntStrict(const char *text, int &outValue) {
  char *endPtr = nullptr;
  long value = strtol(text, &endPtr, 10);
  if (text == endPtr) {
    return false;
  }
  while (*endPtr == ' ' || *endPtr == '\t') {
    endPtr++;
  }
  if (*endPtr != '\0') {
    return false;
  }
  outValue = static_cast<int>(value);
  return true;
}

void handleCommand(char *cmd) {
  char *colon = strchr(cmd, ':');
  if (colon) {
    *colon = '\0';
  }

  char *name = cmd;
  char *valueText = colon ? colon + 1 : nullptr;

  while (*name == ' ' || *name == '\t') {
    name++;
  }

  if (strcmp(name, "STOP") == 0) {
    stopAll();
    lastCommandMs = millis();
    if (PRINT_COMMAND_ACKS) {
      Serial.println("OK:STOP");
    }
    return;
  }

  if (!valueText) {
    Serial.println("ERR:VALUE");
    return;
  }

  int value = 0;
  if (!parseIntStrict(valueText, value)) {
    Serial.println("ERR:VALUE");
    return;
  }

  if (strcmp(name, "STEER") == 0) {
    writeSteering(value);
    lastCommandMs = millis();
    if (PRINT_COMMAND_ACKS) {
      Serial.println("OK:STEER");
    }
  } else if (strcmp(name, "DRIVE") == 0) {
    targetSpeed = clampInt(value, -MOTOR_MAX_PWM, MOTOR_MAX_PWM);
    lastCommandMs = millis();
    if (PRINT_COMMAND_ACKS) {
      Serial.println("OK:DRIVE");
    }
  } else {
    Serial.println("ERR:COMMAND");
  }
}

void readSerialCommands() {
  while (Serial.available() > 0) {
    char c = static_cast<char>(Serial.read());

    if (c == '\n') {
      lineBuf[lineLen] = '\0';
      handleCommand(lineBuf);
      lineLen = 0;
    } else if (c != '\r') {
      if (lineLen < LINE_BUF_SIZE - 1) {
        lineBuf[lineLen++] = c;
      } else {
        lineLen = 0;
        Serial.println("ERR:OVERFLOW");
      }
    }
  }
}

void setup() {
  pinMode(MOTOR_IN1_PIN, OUTPUT);
  pinMode(MOTOR_IN2_PIN, OUTPUT);
  if (!USE_TWO_PWM_MOTOR_DRIVER) {
    pinMode(MOTOR_PWM_PIN, OUTPUT);
  }
  if (USE_ENABLE_PIN) {
    pinMode(ENABLE_PIN, INPUT_PULLUP);
  }

  steeringServo.attach(SERVO_PIN);
  stopAll();

  Serial.begin(9600);
  delay(1500);
  lastCommandMs = millis();
  Serial.println("READY");
}

void loop() {
  readSerialCommands();

  if (millis() - lastCommandMs > COMMAND_TIMEOUT_MS) {
    targetSpeed = 0;
  }

  if (!outputsEnabled()) {
    targetSpeed = 0;
  }

  updateMotorRamp();
  updateSoftwareMotorPwm();
}

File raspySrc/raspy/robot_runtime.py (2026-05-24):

import argparse
import glob
import json
import os
import threading
import time

import cv2
import numpy as np

from control_panel import RobotWebServer
from decision_log import DecisionLogger
from drive_state import StateMachine
from lap_direction import find_round_dir
from settings import ConfigLoader, parse_override_value
from vision_pipeline import Pipeline
from vision_types import Pillar, extract_ROI


def clamp(value, low, high):
  return max(low, min(high, value))


def rect_roi(image, rect):
  h, w = image.shape[:2]
  x = int(clamp(rect.get("x", 0), 0, max(0, w - 1)))
  y = int(clamp(rect.get("y", 0), 0, max(0, h - 1)))
  rw = int(max(1, rect.get("w", w)))
  rh = int(max(1, rect.get("h", h)))
  return extract_ROI(image, [x, y], [min(w, x + rw), min(h, y + rh)])


def portion(mask):
  if mask is None or mask.size == 0:
    return 0.0
  return cv2.countNonZero(mask) / float(mask.shape[0] * mask.shape[1])


def steering_offset_to_servo_angle(offset, control):
  center = int(control.get("servo_center_deg", 90))
  min_angle = int(control.get("servo_min_deg", 15))
  max_angle = int(control.get("servo_max_deg", 165))
  if min_angle > max_angle:
    min_angle, max_angle = max_angle, min_angle
  offset = int(round(offset))
  offset_limit = min(center - min_angle, max_angle - center)
  offset = int(clamp(offset, -offset_limit, offset_limit))
  return int(clamp(center + offset, min_angle, max_angle))


def pillar_snapshot(pillar):
  if pillar is None:
    return None
  return {
    "color": pillar.color,
    "x": int(pillar.screen_x),
    "y": int(pillar.y),
    "width": int(pillar.width),
    "height": int(pillar.height),
    "area": int(pillar.area),
    "raw_area": int(pillar.raw_area),
    "contour_area": round(float(pillar.contour_area), 1),
    "seen_frames": int(pillar.seen_frames),
    "held": bool(pillar.held),
    "ignored": bool(pillar.ignore),
  }


def detect_serial_port(config):
  configured = str(config.get("port", "/dev/ttyACM0"))
  if not config.get("auto_detect", True):
    return configured
  for pattern in ("/dev/ttyACM*", "/dev/ttyUSB*"):
    matches = sorted(glob.glob(pattern))
    if matches:
      return matches[0]
  try:
    import serial.tools.list_ports
    ports = sorted(port.device for port in serial.tools.list_ports.comports())
    if ports:
      return ports[0]
  except Exception:
    pass
  return configured


class ArduinoLink:
  def __init__(self, serial_config, dry_run=False):
    self.config = serial_config
    self.dry_run = dry_run or not bool(serial_config.get("enabled", True))
    self.ser = None
    self.last_command = {}
    self.last_command_at = {}
    self.port = detect_serial_port(serial_config)

  def connect(self):
    if self.dry_run:
      print("Serial disabled; running without Arduino output.")
      return
    try:
      import serial
    except ImportError:
      print("pyserial is not installed; running without Arduino output.")
      self.dry_run = True
      return

    self.ser = serial.Serial(
      self.port,
      int(self.config.get("baud_rate", 9600)),
      timeout=0.2,
      write_timeout=float(self.config.get("write_timeout_seconds", 1.0)),
    )
    try:
      self.ser.reset_input_buffer()
    except Exception:
      pass
    ready = self.wait_ready(float(self.config.get("ready_timeout_seconds", 6.0)))
    print(f"Arduino {'ready' if ready else 'connected'} on {self.port}")

  def wait_ready(self, timeout_seconds):
    deadline = time.monotonic() + timeout_seconds
    while self.ser and time.monotonic() < deadline:
      line = self.ser.readline().decode("ascii", errors="ignore").strip()
      if line == "READY":
        return True
    return False

  def send(self, command, value=None, force=False):
    if value is None:
      text = command
      key = command
    else:
      text = f"{command}:{int(value)}"
      key = command

    now = time.monotonic()
    send_interval = float(self.config.get("send_interval_seconds", 0.02))
    keepalive_interval = float(self.config.get("keepalive_interval_seconds", 0.15))
    last_at = self.last_command_at.get(key, 0.0)
    if not force and self.last_command.get(key) == text and now - last_at < keepalive_interval:
      return
    if not force and self.last_command.get(key) != text and now - last_at < send_interval:
      return

    if self.dry_run:
      self.last_command[key] = text
      self.last_command_at[key] = now
      return
    if not self.ser:
      return
    self.ser.write((text + "\n").encode("ascii"))
    self.ser.flush()
    self.last_command[key] = text
    self.last_command_at[key] = now
    self.drain_input()

  def drain_input(self):
    if not self.ser:
      return
    try:
      while self.ser.in_waiting:
        self.ser.read(self.ser.in_waiting)
    except Exception:
      pass

  def apply(self, servo_angle, drive_speed):
    self.send("STEER", servo_angle)
    self.send("DRIVE", drive_speed)

  def stop(self):
    self.send("STOP", force=True)

  def close(self):
    try:
      self.stop()
    finally:
      if self.ser and self.ser.is_open:
        self.ser.close()


class PiCamera:
  def __init__(self, camera_config):
    self.config = camera_config
    self.picam2 = None

  def start(self):
    try:
      from picamera2 import Picamera2
    except ImportError as exc:
      raise RuntimeError("Picamera2 is not installed. Run this on the Raspberry Pi camera environment.") from exc

    self.picam2 = Picamera2()
    size = (
      int(self.config.get("frame_width", 640)),
      int(self.config.get("frame_height", 480)),
    )
    fmt = self.config.get("format", "RGB888")
    self.picam2.configure(self.picam2.create_preview_configuration(main={"size": size, "format": fmt}))
    self.picam2.start()
    try:
      self.picam2.set_controls({"AwbEnable": bool(self.config.get("awb_enable", False))})
    except Exception:
      pass

  def capture_bgr(self):
    frame = self.picam2.capture_array()
    frame = cv2.cvtColor(frame, cv2.COLOR_RGB2BGR)
    if self.config.get("flip_180", True):
      frame = cv2.rotate(frame, cv2.ROTATE_180)
    return frame

  def stop(self):
    if self.picam2:
      self.picam2.stop()
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

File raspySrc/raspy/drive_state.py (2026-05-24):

import time


class StateMachine:
  def __init__(self, behavior=None):
    self.behavior = behavior or {}
    self.current_state = "STARTING"
    self.last_state_time = time.monotonic()
    self.round_dir = int(self.behavior.get("fixed_round_dir", 0))
    self.turns_left = int(self.behavior.get("turns", 12))
    self.time_diff = 0.0
    self.search_for_dir = self.round_dir == 0
    self._round_dir_votes = 0
    self._scheduled_state = None
    self._scheduled_state_block = False
    self._time_last_avoid = -999.0
    self.next_pillar = None
    self.is_pillar_round = bool(self.behavior.get("pillars", False))

    if self.round_dir != 0:
      self.round_dir = 1 if self.round_dir > 0 else -1

  def transition_state(self, new_state):
    self.current_state = new_state
    self.last_state_time = time.monotonic()

  def schedule_state_transition(self, new_state, delay_seconds, block=True):
    self._scheduled_state = (new_state, time.monotonic() + float(delay_seconds))
    self._scheduled_state_block = block

  def add_round_dir_vote(self, vote):
    if not self.search_for_dir or vote == 0:
      return
    self._round_dir_votes += 1 if vote > 0 else -1
    threshold = int(self.behavior.get("round_dir_vote_threshold", 10))
    if abs(self._round_dir_votes) >= threshold:
      self.round_dir = 1 if self._round_dir_votes > 0 else -1
      self.search_for_dir = False
      self.transition_state("PD-CENTER")

  def should_transition_state(self, portion_orange, portion_blue, pillars):
    now = time.monotonic()
    self.time_diff = now - self.last_state_time

    if self._scheduled_state is not None:
      new_state, scheduled_time = self._scheduled_state
      if now >= scheduled_time:
        self.transition_state(new_state)
        self._scheduled_state = None
        return True
      if self._scheduled_state_block:
        return False

    if self.current_state == "STARTING":
      if pillars and self.is_pillar_round:
        next_pillar = pillars[0]
        area = next_pillar.area
        seen_frames = int(getattr(next_pillar, "seen_frames", 1))
        if (
          area > self.behavior.get("pillar_track_area", 190)
          and seen_frames >= self.behavior.get("pillar_track_confirm_frames", 1)
          and not next_pillar.ignore
        ):
          self.next_pillar = next_pillar
          self.transition_state("TRACKING-PILLAR")
          return True
      if self.round_dir != 0 and not self.search_for_dir:
        self.transition_state("PD-CENTER")
        return True
      return False

    if self.current_state == "PD-CENTER" and self.turns_left <= 0 and self._scheduled_state is None:
      self.schedule_state_transition(
        "DONE",
        self.behavior.get("finish_delay_seconds", 3.1),
        False,
      )
      return True

    if (
      self.current_state in ("TURNING-L", "TURNING-R", "PD-CENTER")
      and self.time_diff < self.behavior.get("state_hold_seconds", 0.4)
    ):
      return False

    if pillars and self.is_pillar_round:
      next_pillar = pillars[0]
      area = next_pillar.area
      seen_frames = int(getattr(next_pillar, "seen_frames", 1))
      if self.current_state == "PD-CENTER":
        self.next_pillar = next_pillar
        if (
          area > self.behavior.get("pillar_track_area", 190)
          and seen_frames >= self.behavior.get("pillar_track_confirm_frames", 1)
          and not next_pillar.ignore
        ):
          self.transition_state("TRACKING-PILLAR")
          return True
      elif self.current_state in ("TRACKING-PILLAR", "PD-CENTER"):
        if (
          area > self.behavior.get("pillar_avoid_area", 530)
          and seen_frames >= self.behavior.get("pillar_avoid_confirm_frames", 1)
          and now - self._time_last_avoid > self.behavior.get("pillar_avoid_cooldown_seconds", 1.0)
        ):
          self.transition_state("AVOIDING-R" if next_pillar.color == "RED" else "AVOIDING-G")
          self.next_pillar = None
          return True

    if self.current_state == "TRACKING-PILLAR" and not pillars:
      self.transition_state("PD-CENTER")
      return True

    if self.current_state in ("AVOIDING-R", "AVOIDING-G"):
      if self.time_diff > self.behavior.get("pillar_avoid_seconds", 2.5):
        self.transition_state("PD-CENTER")
        self._time_last_avoid = now
        return True

    if self.current_state in ("TURNING-L", "TURNING-R"):
      if self.time_diff > self.behavior.get("turn_timeout_seconds", 0.85):
        self.transition_state("PD-CENTER")
        return True
      return False

    min_portion = self.behavior.get("line_marker_min_portion", 0.25)
    if portion_blue > min_portion:
      if self.current_state != "TURNING-R" and self.round_dir < 0:
        self.turns_left -= 1
        delay = self.behavior.get(
          "pillar_turn_delay_seconds" if self.is_pillar_round else "turn_delay_seconds",
          0.3 if self.is_pillar_round else 0.7,
        )
        self.schedule_state_transition("TURNING-L", delay)
      else:
        self.transition_state("PD-CENTER")
      return True

    if portion_orange > min_portion:
      if self.current_state != "TURNING-L" and self.round_dir > 0:
        self.turns_left -= 1
        delay = self.behavior.get(
          "pillar_turn_delay_seconds" if self.is_pillar_round else "turn_delay_seconds",
          0.3 if self.is_pillar_round else 0.7,
        )
        self.schedule_state_transition("TURNING-R", delay)
      else:
        self.transition_state("PD-CENTER")
      return True

    return False

  # Backwards-compatible names for older scripts.
  def transitionState(self, new_state):
    return self.transition_state(new_state)

  def scheduleStateTransition(self, new_state, time_diff, block=True):
    return self.schedule_state_transition(new_state, time_diff, block)

  def shouldTransitionState(self, portion_orange, portion_blue, pillars):
    return self.should_transition_state(portion_orange, portion_blue, pillars)

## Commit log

2026-04-06 Preliminary Commit
    Current progress documentation
2026-04-06 Update readme.md
    added photos and videos for first lego prototype
2026-04-28 Update README with project progress details
    Added current progress section detailing the robot's chassis design and motor incorporation.
2026-05-05 Update readme with current progress on robot
    Added updates on robot assembly and current coding efforts.
2026-05-06 Update servo code && publish main motor code
2026-05-06 Update readme.md(90’a kadar)
2026-05-06 Create Pi Serial Arduino Interface Code && Fixed Bugs of main.ino
    [main.cpp]
2026-05-08 Update readme with project progress and details
    Added details about wall tracking code and robot chassis assembly.
2026-05-13 Revise readme for hardware and software updates
    Updated the readme to reflect changes in hardware and software components, including switching from an Arduino Uno to an Arduino Nano for improved latency, and adjustments to sensor counts and wiring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
2026-05-14 Revise engineering journal and 3D-printed parts details
    Updated compatibility notes and added details about the 3D-printed parts, including improvements made to enhance durability.
2026-05-14 Publish .stl files of chassis and adapters
    [adapters.stl, chassis.stl]
2026-05-19 Publish Schematics
    [wro.fzz]
2026-05-19 Update README with Schematics
    Updated images of the circuitry in the README.
2026-05-23 Add servo_adapter.stl
    [servo_adapter.stl]
2026-05-24 Revise front photo to include new lens
2026-05-24 Enhance camera section with lens details
    Added details about the use of a clip-on wide-angle lens for the Raspberry Pi Camera 3 to improve obstacle detection.
2026-05-24 Add camera lens details to README
    Added camera lens information to the specifications.
2026-05-24 Create engineer
    Added a note indicating the journal is out of date and to refer to README.md for current status.
2026-05-24 Add npm package v1.0.0 with Raspberry and Arduino proxy sources
    Agent-Logs-Url: https://github.com/berkemutluu/Flame-WRO-FE/sessions/3019378a-ff80-45c2-9760-5820a6687c2e
2026-05-24 Fix case of README.md in package.json
